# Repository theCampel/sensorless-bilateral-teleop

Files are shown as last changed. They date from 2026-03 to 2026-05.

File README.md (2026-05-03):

# Sensorless Bilateral Force Feedback for Low-Cost Scaled Teleoperation

A low-cost bimanual teleoperation platform that gives the operator bilateral force feedback without dedicated force sensors. Two commodity leader arms control two custom 2x-scaled 3D-printed follower arms; contact resistance is estimated from Dynamixel motor current and reflected back to the operator.

**[Preprint PDF](sensorless-bilateral-teleop.pdf)** | **[DOI](https://doi.org/10.13140/RG.2.2.31526.28487)** | **[Video](https://youtu.be/PqzKTUld3uw)** | **[Project page](https://leocamacho.co/teleop)**

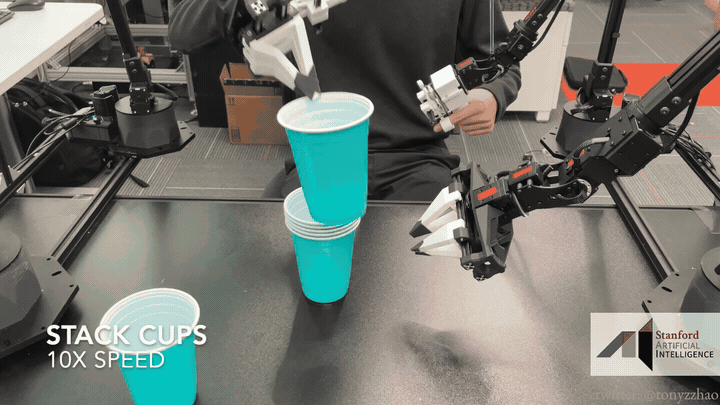
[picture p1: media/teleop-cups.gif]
The teleoperation system stacking cups with sensorless force feedback


## Key Results

- **91.1% obstacle detection sensitivity** via sensorless force feedback (n=22 user study)
- **~$3,000 total cost** for the complete dual-pair system (10x cheaper than ALOHA)
- **55% motor cost savings** via torque-tiered actuator selection
- **7/7 median learnability** rating from novice users

## Why It Matters

Low-cost imitation-learning systems such as ALOHA, GELLO, and the Koch arm made teleoperation cheaper, but most affordable platforms still lack haptic feedback. This project explores a narrower question: how far can bilateral feedback go if the only force signal available is motor current from commodity servos?

The answer is useful but bounded. Motor current is strong enough for operators to feel contact and detect hidden obstacles, but it cannot reliably distinguish gravity load from external contact without a dynamics model. The repository includes the ROS 2 control stack, 3D-printable follower arm links, the preprint, and the scripts used to create the README demo media.

## System Overview

| Component | Specification |
|---|---|
| Leaders (x2) | PincherX-100, all XL430-W250 motors, PWM mode (backdrivable) |
| Followers (x2) | Custom 2x-scaled, XM430-W210 (shoulder/elbow) + XL430-W250 (waist/wrist/gripper), position mode |
| Force feedback | Motor current as force proxy, 300 mA threshold, proportional PWM resistance |
| Software | ROS 2 Humble, 20 nodes across 4 namespaces, 100 Hz joint state publishing |
| Safety | Graceful shutdown (POSIX signal masking), smooth startup, gripper PWM limiting, invisible wall collision avoidance |

## Repository Structure

```
├── paper/                          # Preprint and figures
│   ├── paper.tex                   # LaTeX source
│   ├── paper.pdf                   # Compiled paper
│   ├── references.bib              # Bibliography
│   └── figures/                    # Paper figures
│
├── media/
│   └── teleop-cups.gif             # README demo GIF
│
├── scripts/
│   └── make_readme_gif.py          # Frame-range GIF generation helper
│
├── dissertation_ws/                # ROS 2 workspace
│   └── src/teleop_controller/
│       ├── teleop_controller/      # Python source
│       │   ├── teleop_node.py      # Joint-space teleoperation + collision avoidance
│       │   ├── force_feedback_node.py  # Sensorless bilateral force feedback
│       │   ├── motion_node.py      # Shared autonomy (RViz interactive markers)
│       │   └── effort_graph_node.py    # Real-time effort visualisation
│       ├── config/                 # Motor configs, teleop params, RViz config
│       ├── launch/                 # dual_arm_bringup.launch.py
│       └── urdf/                   # Scaled follower robot description
│
├── 3d-printing/                    # 3D printing files
│   ├── modified_arm/               # Custom 2x-scaled STLs (final versions)
│   │   ├── left-bicep.stl
│   │   ├── right-bicep.stl
│   │   ├── final-final-xl-forearm.stl
│   │   ├── left-final-gripper.stl
│   │   ├── right-final-gripper.stl
│   │   ├── left-finger-hold.stl
│   │   └── right-finger-hold.stl
│   └── px100-meshes/               # Original PincherX-100 reference meshes
│
└── identify_arms.py                # USB serial port identification utility
```

## Hardware Requirements

- 2x PincherX-100 Robot Arms (leaders)
- 4x XM430-W210 motors (follower shoulder + elbow)
- 6x XL430-W250 motors (follower waist + wrist + gripper)
- 4x U2D2 USB-to-serial adapters
- 12V power supply
- 3D-printed follower arm links (STLs in `3d-printing/modified_arm/`)

## Quick Start

### Prerequisites
- Ubuntu 22.04 with ROS 2 Humble
- [Interbotix XS SDK](https://docs.trossenrobotics.com/interbotix_xsarms_docs/)

### Set up USB latency and udev rules
```bash
python3 identify_arms.py
```

### Build and run
```bash
cd dissertation_ws
colcon build --packages-select teleop_controller
source install/setup.bash
ros2 launch teleop_controller dual_arm_bringup.launch.py
```

### Debug
```bash
ros2 node list
ros2 topic echo /leader_left/joint_states
ros2 topic echo /follower_left/joint_states
```

## Configuration

Teleoperation parameters are in `dissertation_ws/src/teleop_controller/config/teleop_config.yaml`:

| Parameter | Default | Description |
|---|---|---|
| `effort_threshold` | 300 mA | Effort below this is filtered |
| `pwm_scale` | 0.5 | Proportional gain for force feedback |
| `max_pwm` | 350 | Safety cap on leader resistance |
| `smoothing_alpha` | 0.15 | Exponential smoothing factor |
| `wall_threshold` | 0.0 m | Y-position of invisible wall |

## README Media

The demo GIF is generated from the full teleoperation video using a frame range:

```bash
python3 scripts/make_readme_gif.py /path/to/teleop_all.mp4 media/teleop-cups.gif \
  --start-frame 3000 \
  --end-frame 3180
```

## Citation

```bibtex
@misc{camacho2026sensorless,
  title={Sensorless Bilateral Force Feedback for Low-Cost Scaled Teleoperation},
  author={Camacho Pel\'aez, Leonardo},
  year={2026},
  doi={10.13140/RG.2.2.31526.28487},
  url={https://doi.org/10.13140/RG.2.2.31526.28487}
}
```

## License

This project is open-source. Hardware designs (STL files) and software are provided for research and educational use.

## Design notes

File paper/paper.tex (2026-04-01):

\documentclass[conference]{IEEEtran}

\usepackage{graphicx}
\usepackage{amsmath}
\usepackage{amssymb}
\usepackage{booktabs}
\usepackage{xcolor}
\usepackage{hyperref}
\usepackage{siunitx}
\usepackage{multirow}
\usepackage{subcaption}
\usepackage[font=small]{caption}
\usepackage{pifont}

\hypersetup{
  colorlinks=true,
  linkcolor=black,
  citecolor=[rgb]{0.0,0.35,0.65},
  urlcolor=[rgb]{0.0,0.35,0.65}
}

\title{Sensorless Bilateral Force Feedback for\\Low-Cost Scaled Teleoperation}

\author{\IEEEauthorblockN{Leonardo Camacho Pel\'{a}ez}
\IEEEauthorblockA{University of Edinburgh\\
\texttt{leocamacho707@gmail.com}}}

\makeatletter
\ifCLASSOPTIONconference
\def\@maketitle{\newpage
\bgroup\par\vskip\IEEEtitletopspace\vskip\IEEEtitletopspaceextra\centering%
   \vskip0.2em{\Huge\ifCLASSOPTIONtransmag\bfseries\LARGE\fi\@IEEEcompsoconly{\sffamily}\@IEEEcompsocconfonly{\normalfont\normalsize\vskip 2\@IEEEnormalsizeunitybaselineskip
   \bfseries\Large}\@IEEEcompsocnotconfonly{\vskip 0.75\@IEEEnormalsizeunitybaselineskip}\@title\par}\relax
   \@IEEEcompsocnotconfonly{\vskip 0.5\@IEEEnormalsizeunitybaselineskip}\vskip1.0em\par%
   {\@IEEEspecialpapernotice\mbox{}\vskip\@IEEEauthorblockconfadjspace%
    \mbox{}\hfill\begin{@IEEEauthorhalign}\@author\end{@IEEEauthorhalign}\hfill\mbox{}\par}\relax
   \vskip 1.2em
   \begin{minipage}{\textwidth}
      \centering
      
      \par\vspace{0.35em}
      {\footnotesize Fig.~1: \textbf{System overview.} (A)~The operator controls a PincherX-100 leader arm while the 2$\times$-scaled follower contacts an obstacle. (B)~Motor effort readings from the follower arm during obstacle contact: shoulder effort (dark) exceeds the 300\,mA feedback threshold (dashed), triggering proportional resistance at the leader. (C)~RViz visualisation showing leader and follower arm states in real time.\par}
   \end{minipage}\par
\par\addvspace{0.5\baselineskip}\egroup}
\fi
\makeatother

\begin{document}

\maketitle
\setcounter{figure}{0}
\refstepcounter{figure}\label{fig:hero}

% ===== ABSTRACT =====
\begin{abstract}
We present a bilateral teleoperation system in which two small commodity leader arms control two 3D-printed follower arms at twice the scale.
The followers use torque-tiered actuators---high-torque motors only at joints that demand them---saving 55\% on motor costs.
The complete four-arm platform costs approximately \$3{,}000, an order of magnitude less than comparable systems.
Unlike recent low-cost platforms (ALOHA, GELLO, Koch arm), ours provides force feedback: the leader arm experiences resistance when the follower contacts an object.
This is achieved exclusively using motor current as a force proxy, with no dedicated sensors.
In a study with 22 participants, operators detected real obstacles through force feedback with 91\% mean sensitivity and rated learnability at the maximum score (median 7/7).
The primary limitation is that motor current cannot distinguish gravity from contact---an extended arm produces the same signal as a collision.
We tested three alternative feedback policies to resolve this; each failed for a different physical reason, confirming that a dynamics model is required.
All source code, CAD files, and hardware documentation are released as open source at \url{https://leocamacho.co/teleop}.
\end{abstract}

% ===== INTRODUCTION =====
\section{Introduction}

In 1949, Raymond Goertz built the first mechanical bilateral manipulator at Argonne National Laboratory, allowing a human operator to handle radioactive materials while feeling the forces encountered by the remote arm~\cite{goertz1949}. Five years later, Goertz replaced the mechanical linkage with electrical servo coupling~\cite{goertz1954}, establishing the fundamental architecture that bilateral teleoperators still follow today: a leader arm that the operator moves, a follower arm that tracks it, and a feedback channel that communicates environment forces back to the operator's hand.

For decades, this architecture required industrial-grade hardware. A recent wave of low-cost systems has begun to change this. ALOHA~\cite{zhao2023aloha} demonstrated fine bimanual manipulation for approximately \$20,000 using commodity arms. GELLO~\cite{wu_2024_gello} built kinematically-matched leaders for under \$300. The Koch arm~\cite{koch2024} pushed the cost of a single leader-follower pair below \$250. These systems have enabled imitation learning at previously impossible scale.

However, all of these systems are \emph{unilateral}: the operator moves the leader, the follower tracks, and that is all. There is no force feedback channel. The reason is straightforward: bilateral control traditionally requires force/torque sensors (\$4,000--10,000 each) or carefully calibrated dynamics models. Neither is practical on commodity servo hardware. Recent concurrent work has begun to explore this gap~\cite{echo2025, sujit_2025_improving, kobayashi2024, kanai2025}, but a complete, low-cost bilateral system with custom-scaled hardware and an honest characterisation of its limits has been lacking.

We present a system that closes this gap by using motor current as a force proxy. Our contributions are:

\begin{enumerate}
    \item \textbf{Sensorless bilateral force feedback} on commodity Dynamixel servos, using motor current readings as a proportional force proxy. We achieve 91.1\% obstacle detection sensitivity in a user study without any dedicated force sensors. We characterise the electromagnetic braking effect that makes naive implementations fail.

    \item \textbf{Custom 2$\times$-scaled follower arms} with 3D-printed links and a torque-tiered motor configuration (high-torque XM430 at shoulder/elbow, low-torque XL430 elsewhere), reducing per-follower motor cost by 55\% versus a uniform design.

    \item \textbf{A complete dual-pair bimanual system} at $\sim$\$3,000 total---an order of magnitude cheaper than ALOHA---with collision avoidance, graceful shutdown, smooth startup, and shared autonomy.

    \item \textbf{An empirical characterisation of the gravity-contact ambiguity}: we evaluate three alternative feedback policies for handling gravity-induced false positives, each failing for a distinct physical reason, and identify model-based gravity compensation as the established solution.
\end{enumerate}

All hardware designs, source code, and CAD files are publicly available.\footnote{\url{https://github.com/theCampel/sensorless-bilateral-teleop}}

% ===== RELATED WORK =====
\section{Related Work}

\subsection{Low-Cost Teleoperation}

The past two years have seen rapid progress in accessible teleoperation. ALOHA~\cite{zhao2023aloha} paired ViperX-300 followers with custom Dynamixel-based leaders for bimanual manipulation, enabling Action Chunking with Transformers (ACT) for imitation learning. GELLO~\cite{wu_2024_gello} built 3D-printed kinematically-matched leaders for Franka, UR5, and xArm followers at under \$300 per leader. The Koch arm~\cite{koch2024} demonstrated that a single pair could be built for under \$250. U-ARM~\cite{zou_2025_uarm} and LeRobot~\cite{lerobot2025} further pushed accessibility.

All of these systems are unilateral. The operator sends commands; the follower executes them; there is no return channel. Our work adds bilateral force feedback to this class of system using only the hardware already present.

\subsection{Bilateral Control}

Bilateral teleoperation has a long theoretical history. Lawrence~\cite{lawrence_1993_stability} established the fundamental stability-transparency trade-off: perfect force transparency requires infinite controller stiffness, which is inherently destabilising. The four-channel bilateral architecture~\cite{hokayem2006} and wave variable methods~\cite{anderson1989} address time-delay stability but assume force sensing at both ends. Impedance control~\cite{hogan1985} provides a framework for contact interaction but again typically requires force measurements.

On commodity servo hardware, dedicated force sensors are impractical. Recent concurrent work has begun exploring sensorless alternatives: GELLO+Force~\cite{sujit_2025_improving} augments GELLO with strain-gauge-based force sensing on a Franka Panda, Bi-ACT~\cite{kobayashi2024} demonstrates the importance of bilateral feedback for imitation learning quality using disturbance observers at 1\,kHz, Echo~\cite{echo2025} proposes open-source force feedback, and IGBT~\cite{kanai2025} achieves sensorless bilateral control by clamping leader commands by follower effort magnitude. Our work differs in using only the motor current readings already available on standard Dynamixel servos, requiring no additional sensing hardware, and in building custom-scaled followers rather than using commercial off-the-shelf arms.

\subsection{Motor Current as Force Proxy}

Using motor current (or torque) as a proxy for external forces is well-established in industrial robotics~\cite{morante2016}. The approach works because motor current is proportional to torque output, which includes both the desired motion torque and any external disturbance. Matsumoto et al.~\cite{fast_bilateral2025} recently demonstrated fast bilateral teleoperation using accurate dynamics models for sensorless force estimation. However, without a dynamics model, the raw current signal includes gravitational, inertial, and frictional components that cannot be separated from external contact forces---a limitation we characterise in detail.

% ===== SYSTEM DESIGN =====
\section{System Design}

\subsection{Overview}

Our system consists of two leader-follower pairs operating simultaneously (Fig.~\ref{fig:hero}). Each pair comprises a standard PincherX-100~\cite{px100specs} leader arm (5-DOF, all XL430-W250 motors~\cite{xl430manual}) and a custom 2$\times$-scaled follower arm. The leaders operate in PWM mode (backdrivable), while the followers operate in position mode, tracking leader joint angles via 1:1 joint-space mapping. A software-based invisible wall at the workspace centreline prevents the two followers from colliding. The entire system runs on ROS~2 Humble~\cite{macenski_2022_robot}.

\subsection{Custom Scaled Followers}

Rather than purchasing larger commercial arms, we designed and 3D-printed custom follower arms at 2$\times$ the PincherX-100's link lengths (Fig.~\ref{fig:hardware}). This required decomposing the original STL meshes into motor mounts (kept at original scale to fit unmodified motors) and arm segments (scaled 2$\times$). Naive uniform scaling would have enlarged the motor cavities beyond the physical motor dimensions.

\textbf{Torque-tiered motor selection.}
Scaling laws dictate that bending moments at joints grow with the square of link length~\cite{waldron2000, dermitzakis2011}. At 2$\times$ scale, the shoulder and elbow joints require roughly 4$\times$ the torque of the original PincherX-100. We address this with a mixed-motor design:

\begin{itemize}
    \item \textbf{Shoulder and elbow}: XM430-W210 motors~\cite{xm430manual} (3.0\,Nm stall torque, \$333 each)
    \item \textbf{Waist, wrist, and gripper}: XL430-W250 motors~\cite{xl430manual} (1.5\,Nm stall torque, \$27.50 each)
\end{itemize}

This torque-tiered approach costs \$749 per follower in motors, compared to \$1,665 for uniform XM430s---a 55\% reduction. The complete dual-pair system (4 arms, power supplies, USB adapters, 3D-printed parts) totals approximately \$3,000.

\begin{figure}[t]
    \centering
    
    \caption{\textbf{Hardware comparison.} Standard PincherX-100 leader (right) alongside the custom 2$\times$-scaled follower (left). High-torque XM430 motors (green labels) at shoulder and elbow handle the increased loads; lower-cost XL430 motors serve the remaining joints.}
    \label{fig:hardware}
\end{figure}

\subsection{Software Architecture}

The system comprises 10 ROS~2 nodes per arm pair (20 total), each in an explicit namespace to prevent topic collisions:

\begin{itemize}
    \item \texttt{xs\_sdk} nodes for leader and follower motor control (100\,Hz joint state publishing)
    \item \texttt{robot\_state\_publisher} nodes for TF frame broadcasting
    \item \texttt{teleop\_node} for joint-space mapping and collision avoidance
    \item \texttt{force\_feedback\_node} for bilateral current-based feedback
    \item \texttt{motion\_node} for shared autonomy via RViz interactive markers
\end{itemize}

USB serial latency is set to 1\,ms (from the 16\,ms default~\cite{ftdi_latency}) via persistent \texttt{udev} rules. Each arm has a dedicated serial port mapped deterministically to \texttt{/dev/ttyDXL\{0--3\}}.

\subsection{Sensorless Force Feedback}
\label{sec:force_feedback}

Our bilateral force feedback uses motor current (``effort'' in Dynamixel terminology) as a proxy for external forces. The follower's \texttt{xs\_sdk} publishes effort values (in mA) for each joint at 100\,Hz. The force feedback node applies a proportional resistance law:

\begin{equation}
    \text{PWM}_{\text{leader},j} = \begin{cases}
        -\text{sgn}(e_j) \cdot \min\!\big((|e_j| - \theta) \cdot k,\; P_{\max}\big) & \text{if } |e_j| > \theta \\
        0 & \text{otherwise}
    \end{cases}
    \label{eq:feedback}
\end{equation}

where $e_j$ is the follower effort on joint $j$, $\theta = 300$\,mA is the effort threshold (filtering noise and low-load motion), $k = 0.5$ is the proportional gain, and $P_{\max} = 350$ is a safety cap ($\approx$40\% of the $\pm$885 PWM range). The resulting PWM is exponentially smoothed with $\alpha = 0.15$ before being sent to the leader motor as a resisting torque. The leader must be in PWM mode with torque enabled for this to work, which introduces electromagnetic braking as a side effect (Section~\ref{sec:gravity}).

\textbf{Electromagnetic braking trade-off.} Enabling torque on the leader motors (required for PWM-based force feedback) introduces electromagnetic braking via slow-decay H-bridge behaviour~\cite{srikanth2008, colgate1994}. When the motor is backdriven, back-EMF through the H-bridge creates a velocity-dependent resistance amplified by $N^2$ through the gearbox---for the XL430's 258.5:1 ratio, this amplification is approximately 67{,}000. This increases the baseline resistance the operator feels, reducing backdrivability. This is a hardware-level manifestation of Lawrence's stability-transparency trade-off~\cite{lawrence_1993_stability}: force feedback requires torque-enabled motors, which reduces transparency. ALOHA\,2~\cite{aloha2_2024} addressed a similar problem by replacing the leader gripper motor with a lower gear-ratio variant, achieving a 10$\times$ reduction in backdriving force.

\subsection{Safety Systems}

Three safety mechanisms protect the hardware:

\textbf{Graceful shutdown.} The follower \texttt{xs\_sdk} processes are launched with POSIX \texttt{SIG\_BLOCK} signal masks, preventing Ctrl+C from killing the motor controller before the teleop node can command a smooth return to the sleep position over 1.5\,s. This prevents the 2$\times$-scaled arms from crashing under their own weight.

\textbf{Smooth startup.} On the first leader message, the follower's Profile Velocity is temporarily set to 1,500\,ms (slow), allowing a gradual move to the leader's position before restoring the responsive 50\,ms setting.

\textbf{Gripper protection.} A hardware PWM limit of 300 ($\sim$34\% of maximum) is set on follower gripper motors to prevent stalling when gripping objects harder than the leader can close.

\subsection{Collision Avoidance}

A software-based invisible wall at the workspace centreline ($Y = 0$) prevents the two followers from colliding during bimanual operation. Each teleop node queries the TF tree~\cite{foote2013tf} for its follower's gripper position at 30\,Hz. When the gripper crosses the wall threshold, all follower joints are frozen. Resumption uses 5\% per-frame blending of the leader's target position to prevent jerky snap-back when the operator retreats.

% ===== EXPERIMENTS =====
\section{Experiments}

\subsection{Study Design}

We conducted a user study with 22 participants (university students, ages 18--24, no prior teleoperation experience) to evaluate the force feedback system. The study comprised:

\begin{enumerate}
    \item A \textbf{perception survey} (5 questions, 7-point Likert scale~\cite{preston2000}) assessing the operator's subjective experience of force feedback.
    \item An \textbf{obstacle detection task} ($n = 14$ with per-trial data) where participants reported whether they felt an obstacle during each of six teleoperation trials (three with obstacles, three without).
\end{enumerate}

Participants received a brief demonstration and 2 minutes of free practice before the evaluation.

\subsection{Perception Results}

Table~\ref{fig:survey} summarises the Likert responses. The strongest result was \textbf{learnability} (Q4: ``The system was easy to learn''): median 7/7, with 14 of 22 participants giving the maximum rating. Participants also rated obstacle detection positively (Q1: median 6/7) and found the feedback useful for task awareness (Q3: median 6/7). The lowest-rated item was Q2 (``I could distinguish obstacles from general stiffness''), reflecting the gravity-contact ambiguity discussed in Section~\ref{sec:gravity}.

\begin{table}[t]
    \centering
    \caption{Perception survey results ($n = 22$, 7-point Likert scale).}
    \label{fig:survey}
    \small
    \begin{tabular}{@{}lcccc@{}}
        \toprule
        \textbf{Question} & \textbf{Med.} & \textbf{IQR} & \textbf{Mean} & \textbf{SD} \\
        \midrule
        Q1: Could feel contact & 6 & 1.0 & 6.23 & 0.81 \\
        Q2: Distinguish obstacle from stiffness & 6 & 2.0 & 5.64 & 1.26 \\
        Q3: Feedback useful for awareness & 6 & 1.0 & 6.09 & 0.97 \\
        Q4: System easy to learn & \textbf{7} & 1.0 & \textbf{6.50} & 0.80 \\
        Q5: Felt in control & 6 & 2.0 & 5.91 & 0.87 \\
        \bottomrule
    \end{tabular}
\end{table}

\subsection{Obstacle Detection Performance}

Of the 14 participants with per-trial obstacle detection data (84 total trials):

\begin{itemize}
    \item \textbf{Sensitivity}: 91.1\% $\pm$ 14.8\% (obstacle present, correctly detected)
    \item \textbf{Specificity}: 81.0\% $\pm$ 33.9\% (no obstacle, correctly identified)
    \item \textbf{Accuracy}: 85.7\% $\pm$ 18.3\%
\end{itemize}

Seven participants achieved perfect accuracy on all trials. The variance in specificity is explained by the gravity problem: four participants had elevated false positive rates, reporting obstacles when none were present but the arm was in an extended posture generating high gravitational effort.

\subsection{Qualitative Feedback}

Thematic analysis of open-ended responses revealed five themes: gripper difficulty (10/22 mentions---the dominant complaint, attributable to gearbox friction in the XL430's 258.5:1 gearbox rather than force feedback design), gravity/resistance confusion (6/22), positive usability (5/22: ``very intuitive,'' ``very responsive''), fear of hardware damage (2/22), and ergonomic concerns (2/22). The gripper complaint concerns the leader arm's physical ergonomics, not the teleoperation control or force feedback algorithm.

% ===== THE GRAVITY PROBLEM =====
\section{The Gravity-Contact Ambiguity}
\label{sec:gravity}

The central limitation of sensorless bilateral feedback on commodity hardware is that motor current conflates multiple physical phenomena: gravitational torque, contact forces, friction, inertia, and electromagnetic braking. The proportional effort approach (Section~\ref{sec:force_feedback}) works well for obstacles at non-extreme postures but triggers false feedback when the arm is extended horizontally, where gravity alone produces 400--600\,mA at the shoulder (Fig.~\ref{fig:effort_comparison}).

\begin{figure}[t]
    \centering
    \begin{subfigure}[b]{\columnwidth}
        \centering
        
        \caption{Obstacle contact: shoulder effort exceeds the 300\,mA threshold.}
        \label{fig:effort_contact}
    \end{subfigure}
    \vspace{0.3em}
    \begin{subfigure}[b]{\columnwidth}
        \centering
        
        \caption{Gravity false positive: arm extended horizontally with no obstacle, shoulder effort sustained above threshold due to gravitational load alone.}
        \label{fig:effort_gravity}
    \end{subfigure}
    \caption{\textbf{The gravity-contact ambiguity.} Both scenarios produce effort readings above the 300\,mA feedback threshold (dashed line), but only (a) involves actual obstacle contact. Motor current alone cannot distinguish between these cases.}
    \label{fig:effort_comparison}
\end{figure}

We attempted three alternative gating strategies, each addressing a different aspect of the problem.

\textbf{1. Effort derivative gating}: react to the \emph{rate of change} of follower effort rather than its absolute magnitude, hypothesising that contact produces rapid spikes while gravity changes slowly. This filtered some gravity false positives during slow movements but failed on slow or compliant contacts, which produce small derivatives indistinguishable from normal gravity variation. Differentiating the signal also amplifies sensor noise, producing jittery feedback that requires heavy smoothing---reintroducing the latency this approach was meant to avoid.

\textbf{2. Position error detection}: monitor the tracking error between leader and follower joint angles. If the follower falls behind (cannot reach the commanded position), something is blocking it. This partly solves the gravity problem---the follower still tracks under gravitational load, so the error stays small. But feedback is sluggish: error accumulates only \emph{after} the follower physically fails to track, introducing latency that makes the system feel unresponsive.

\textbf{3. Follower velocity detection}: apply resistance only when the follower has near-zero velocity and high effort---the condition indicating a physical obstacle. During motion under gravity, the follower tracks the leader (non-zero velocity), so no false positive occurs. But whenever the operator \emph{pauses} with the arm extended, zero velocity plus high effort from gravity is indistinguishable from zero velocity plus high effort from an obstacle.

The common failure mode is clear: the combined motor current signal $e_j$ includes a gravitational component $g_j(\mathbf{q})$ that depends on joint configuration $\mathbf{q}$. Without computing $g_j(\mathbf{q})$ via inverse dynamics (e.g., Recursive Newton-Euler~\cite{lynch2017modern}), there is no way to isolate the contact force component. This explains why industrial bilateral systems use either dedicated force sensors or accurate dynamics models~\cite{fast_bilateral2025}---and why existing low-cost systems have avoided bilateral feedback entirely.

We consider this characterisation itself a contribution: it establishes a \emph{necessary condition} for robust sensorless bilateral control and explains clearly why commodity servos cannot achieve it without additional computation.

% ===== DISCUSSION =====
\section{Discussion}

\subsection{Comparison with Existing Systems}

Table~\ref{tab:comparison} positions our system against related work. We are, to our knowledge, the only system that combines custom-built scaled followers, bilateral force feedback, and bimanual operation below \$5,000.

\begin{table}[t]
    \centering
    \caption{Comparison with recent low-cost teleoperation systems, with costs normalised to a dual-pair configuration where possible.}
    \label{tab:comparison}
    \small
    \begin{tabular}{@{}lccccc@{}}
        \toprule
        \textbf{System} & \textbf{Cost} & \textbf{Bi.} & \textbf{Bim.} & \textbf{Custom} & \textbf{F/T} \\
        \midrule
        ALOHA~\cite{zhao2023aloha} & \$20k & \ding{55} & \ding{51} & Leaders & \ding{55} \\
        GELLO~\cite{wu_2024_gello} & $<$\$1k\textsuperscript{*} & \ding{55} & \ding{51} & Leaders & \ding{55} \\
        Koch~\cite{koch2024} & \$860\textsuperscript{\dag} & \ding{55} & \ding{55} & Both & \ding{55} \\
        GELLO+Force~\cite{sujit_2025_improving} & \$60k+\textsuperscript{\dag} & \ding{51} & \ding{55} & Leaders & \ding{51} \\
        IGBT~\cite{kanai2025} & N/R & \ding{51} & \ding{55} & \ding{55} & \ding{55} \\
        Bi-ACT~\cite{kobayashi2024} & \$9k & \ding{51} & \ding{51} & \ding{55} & \ding{55} \\
        \textbf{Ours} & \textbf{\$3k} & \ding{51} & \ding{51} & \textbf{Followers} & \ding{55} \\
        \bottomrule
    \end{tabular}
    \vspace{-0.5em}
    \begin{flushleft}
    \footnotesize Bi.~= Bilateral feedback. Bim.~= Bimanual. F/T~= Dedicated force/torque sensor.\\
    \textsuperscript{*}Leader hardware only; requires a separate follower arm (\$10k--\$45k each).\\
    \textsuperscript{\dag}Extrapolated: single-pair cost $\times$\,2.
    \end{flushleft}
\end{table}

\subsection{Lessons for Systems Builders}

Three practical lessons emerged:

\textbf{Integration dominates.} Individual subsystems (teleop, force feedback, collision avoidance) each worked in isolation. Combining four arms into a single ROS~2 graph exposed namespace leaks, udev conflicts, and startup race conditions that took longer to resolve than any individual feature. The gap between ``one pair works'' and ``two pairs work reliably'' was wider than any individual subsystem challenge.

\textbf{Hardware limitations propagate.} The gripper's gearbox friction (the dominant user complaint) is a mechanical property of the XL430 motor, not a software issue. The mixed motor configuration saved 55\% on costs but prevented uniform gravity compensation: XL430 motors lack the current control mode needed for model-based torque estimation. No amount of algorithmic tuning can fix hardware-fundamental constraints. Identifying \emph{which} limitations are hardware-fundamental versus software-addressable saves engineering time.

\textbf{Negative results are load-bearing.} Our three failed force feedback approaches each reveal a different facet of the gravity-contact ambiguity. Documenting \emph{why} they fail provides more actionable guidance than documenting only the approach that worked.

% ===== CONCLUSION =====
\section{Conclusion}

We presented a low-cost bilateral teleoperation system that achieves sensorless force feedback using motor current readings from commodity Dynamixel servos. The system pairs standard PincherX-100 leaders with custom 2$\times$-scaled 3D-printed followers using a torque-tiered motor design, achieving bimanual bilateral teleoperation at $\sim$\$3,000---an order of magnitude cheaper than comparable systems. A user study demonstrated 91.1\% obstacle detection sensitivity and strong perceived learnability (median 7/7). We characterised the fundamental gravity-contact ambiguity that limits sensorless bilateral control and documented three alternative approaches that fail to resolve it, establishing that a dynamics model is a necessary condition for robust force estimation on commodity hardware.

\textbf{Future work.} Gravity compensation via Recursive Newton-Euler inverse dynamics would address the core limitation. Lower gear-ratio motors or series elastic actuators would reduce electromagnetic braking. The system's 1:1 joint-space mapping and ROS~2 architecture make it directly compatible with imitation learning frameworks such as ACT~\cite{zhao2023aloha} and LeRobot~\cite{lerobot2025}, where bilateral demonstrations could improve policy quality~\cite{kobayashi2024}.

\section*{Acknowledgements}
The author thanks Garry Ellard for supervision and guidance throughout this project, and the 22 user study participants. This work was conducted as a final-year undergraduate dissertation at the University of Edinburgh.

\bibliographystyle{IEEEtran}
\bibliography{references}

\end{document}

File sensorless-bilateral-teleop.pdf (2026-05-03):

# Sensorless Bilateral Force Feedback for Low-Cost Scaled Teleoperation

Leonardo Camacho Pelaez ´
University of Edinburgh
leocamacho707@gmail.com

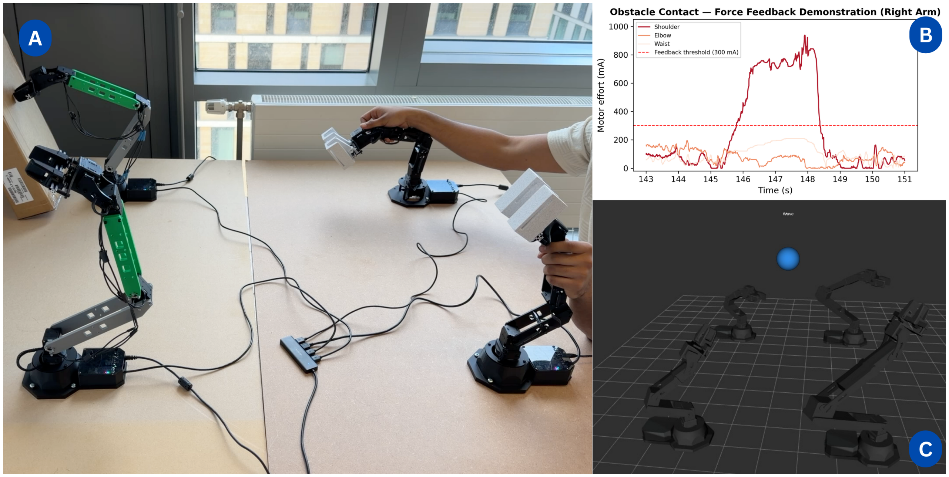
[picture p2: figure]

Fig. 1: System overview. (A) The operator controls a PincherX-100 leader arm while the 2×-scaled follower contacts an obstacle. (B) Motor effort readings from the follower arm during obstacle contact: shoulder effort (dark) exceeds the 300 mA feedback threshold (dashed), triggering proportional resistance at the leader. (C) RViz visualisation showing leader and follower arm states in real time.

Abstract—We present a bilateral teleoperation system in
which two small commodity leader arms control two 3D-printed follower arms at twice the scale. The followers use torque-tiered actuators—high-torque motors only at joints that demand them—saving 55% on motor costs. The complete four-arm platform costs approximately $3,000, an order of magnitude less than comparable systems. Unlike recent low-cost platforms (ALOHA, GELLO, Koch arm), ours provides force feedback: the leader arm experiences resistance when the follower contacts an object. This is achieved exclusively using motor current as a force proxy, with no dedicated sensors. In a study with 22 participants, operators detected real obstacles through force feedback with 91% mean sensitivity and rated learnability at the maximum score (median 7/7). The primary limitation is that motor current cannot distinguish gravity from contact—an extended arm produces the same signal as a collision. We tested three alternative feedback policies to resolve this; each failed for a different physical reason, confirming that a dynamics model is required. All source code, CAD files, and hardware documentation are released as open source at https://leocamacho.co/teleop.
I. INTRODUCTION

In 1949, Raymond Goertz built the first mechanical bilateral manipulator at Argonne National Laboratory, allowing a human operator to handle radioactive materials while feeling the forces encountered by the remote arm [1]. Five years later, Goertz replaced the mechanical linkage with electrical servo coupling [2], establishing the fundamental architecture that bilateral teleoperators still follow today: a leader arm that the operator moves, a follower arm that tracks it, and a feedback channel that communicates environment forces back to the operator’s hand.
For decades, this architecture required industrial-grade hardware. A recent wave of low-cost systems has begun to change this. ALOHA [3] demonstrated fine bimanual manipulation for approximately $20,000 using commodity arms. GELLO [4] built kinematically-matched leaders for under $300. The Koch arm [5] pushed the cost of a single leader-follower pair below $250. These systems have enabled imitation learning at previously impossible scale.

However, all of these systems are unilateral: the operator moves the leader, the follower tracks, and that is all. There is no force feedback channel. The reason is straightforward: bilateral control traditionally requires force/torque sensors ($4,000–10,000 each) or carefully calibrated dynamics models. Neither is practical on commodity servo hardware. Recent concurrent work has begun to explore this gap [6], [7], [8], [9], but a complete, low-cost bilateral system with custom-scaled hardware and an honest characterisation of its limits has been lacking.
We present a system that closes this gap by using motor current as a force proxy. Our contributions are:
1) Sensorless bilateral force feedback on commodity Dynamixel servos, using motor current readings as a proportional force proxy. We achieve 91.1% obstacle detection sensitivity in a user study without any dedicated force sensors. We characterise the electromagnetic braking effect that makes naive implementations fail.
2) Custom 2×-scaled follower arms with 3D-printed links and a torque-tiered motor configuration (high-torque XM430 at shoulder/elbow, low-torque XL430 elsewhere), reducing per-follower motor cost by 55% versus a uniform design.
3) A complete dual-pair bimanual system at ∼$3,000 total—an order of magnitude cheaper than ALOHA— with collision avoidance, graceful shutdown, smooth startup, and shared autonomy.
4) An empirical characterisation of the gravity-contact ambiguity: we evaluate three alternative feedback policies for handling gravity-induced false positives, each failing for a distinct physical reason, and identify model-based gravity compensation as the established solution. All hardware designs, source code, and CAD files are publicly available.¹

II. RELATED WORK
A. Low-Cost Teleoperation
The past two years have seen rapid progress in accessible teleoperation. ALOHA [3] paired ViperX-300 followers with custom Dynamixel-based leaders for bimanual manipulation, enabling Action Chunking with Transformers (ACT) for imitation learning. GELLO [4] built 3D-printed kinematically-matched leaders for Franka, UR5, and xArm followers at under $300 per leader. The Koch arm [5] demonstrated that a single pair could be built for under $250. U-ARM [10] and LeRobot [11] further pushed accessibility.
All of these systems are unilateral. The operator sends commands; the follower executes them; there is no return channel. Our work adds bilateral force feedback to this class of system using only the hardware already present.
B. Bilateral Control
Bilateral teleoperation has a long theoretical history.
Lawrence | [12] | established the | fundamental stability-
transparency trade-off: perfect force transparency requires

1https://github.com/theCampel/sensorless-bilateral-teleop

infinite controller stiffness, which is inherently destabilising. The four-channel bilateral architecture [13] and wave variable methods [14] address time-delay stability but assume force sensing at both ends. Impedance control [15] provides a framework for contact interaction but again typically requires force measurements.
On commodity servo hardware, dedicated force sensors are impractical. Recent concurrent work has begun exploring sensorless alternatives: GELLO+Force [7] augments GELLO with strain-gauge-based force sensing on a Franka Panda, Bi-ACT [8] demonstrates the importance of bilateral feedback for imitation learning quality using disturbance observers at 1 kHz, Echo [6] proposes open-source force feedback, and IGBT [9] achieves sensorless bilateral control by clamping leader commands by follower effort magnitude. Our work differs in using only the motor current readings already available on standard Dynamixel servos, requiring no additional sensing hardware, and in building custom-scaled followers rather than using commercial off-the-shelf arms.
C. Motor Current as Force Proxy
Using motor current (or torque) as a proxy for external forces is well-established in industrial robotics [16]. The approach works because motor current is proportional to torque output, which includes both the desired motion torque and any external disturbance. Matsumoto et al. [17] recently demonstrated fast bilateral teleoperation using accurate dynamics models for sensorless force estimation. However, without a dynamics model, the raw current signal includes gravitational, inertial, and frictional components that cannot be separated from external contact forces—a limitation we characterise in detail.

III. SYSTEM DESIGN

A. Overview
Our system consists of two leader-follower pairs operating simultaneously (Fig. 1). Each pair comprises a standard PincherX-100 [18] leader arm (5-DOF, all XL430-W250 motors [19]) and a custom 2×-scaled follower arm. The leaders operate in PWM mode (backdrivable), while the followers operate in position mode, tracking leader joint angles via 1:1 joint-space mapping. A software-based invisible wall at the workspace centreline prevents the two followers from colliding. The entire system runs on ROS 2 Humble [20].
B. Custom Scaled Followers
Rather than purchasing larger commercial arms, we designed and 3D-printed custom follower arms at 2× the PincherX-100’s link lengths (Fig. 2). This required decomposing the original STL meshes into motor mounts (kept at original scale to fit unmodified motors) and arm segments (scaled 2×). Naive uniform scaling would have enlarged the motor cavities beyond the physical motor dimensions. Torque-tiered motor selection. Scaling laws dictate that bending moments at joints grow with the square of link length [21], [22]. At 2× scale, the shoulder and elbow joints

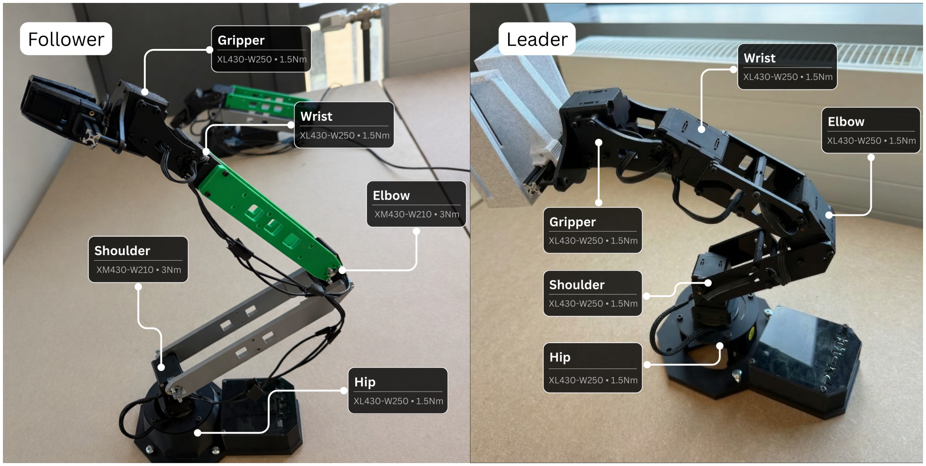
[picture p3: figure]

Fig. 2: Hardware comparison. Standard PincherX-100 leader (right) alongside the custom 2×-scaled follower (left). High-torque XM430 motors (green labels) at shoulder and elbow handle the increased loads; lower-cost XL430 motors serve the remaining joints.

require roughly 4× the torque of the original PincherX-100. We address this with a mixed-motor design:
- Shoulder and elbow: XM430-W210 motors [23] (3.0 Nm stall torque, $333 each)
- Waist, wrist, and gripper: XL430-W250 motors [19] (1.5 Nm stall torque, $27.50 each)
This torque-tiered approach costs $749 per follower in motors, compared to $1,665 for uniform XM430s—a 55% reduction. The complete dual-pair system (4 arms, power supplies, USB adapters, 3D-printed parts) totals approximately $3,000.
C. Software Architecture

The system comprises 10 ROS 2 nodes per arm pair (20 total), each in an explicit namespace to prevent topic collisions:
- xs_sdk nodes for leader and follower motor control (100 Hz joint state publishing)
- robot_state_publisher nodes for TF frame
broadcasting
- teleop_node for joint-space mapping and collision avoidance
- force_feedback_node for bilateral current-based feedback
- motion_node for shared autonomy via RViz interactive markers
USB serial latency is set to 1 ms (from the 16 ms default [24]) via persistent udev rules. Each arm has a dedicated serial port mapped deterministically to
/dev/ttyDXL{0--3}.
D. Sensorless Force Feedback

Our bilateral force feedback uses motor current (“effort” in Dynamixel terminology) as a proxy for external forces. The follower’s xs_sdk publishes effort values (in mA) for each joint at 100 Hz. The force feedback node applies a proportional resistance law:

PWMleader,j =

(
−sgn(ej ) · min
(|ej | − θ) · k, Pmax
if |ej | > θ
0 | otherwise (1)

where ej is the follower effort on joint j, θ = 300 mA is the effort threshold (filtering noise and low-load motion), k = 0.5 is the proportional gain, and Pmax = 350 is a safety cap (≈40% of the ±885 PWM range). The resulting PWM is exponentially smoothed with α = 0.15 before being sent to the leader motor as a resisting torque. The leader must be in PWM mode with torque enabled for this to work, which introduces electromagnetic braking as a side effect (Section V). Electromagnetic braking trade-off. Enabling torque on the leader motors (required for PWM-based force feedback) introduces electromagnetic braking via slow-decay H-bridge behaviour [25], [26]. When the motor is backdriven, back-EMF through the H-bridge creates a velocity-dependent
resistance amplified by N² | through the gearbox—for the
XL430’s 258.5:1 ratio, this amplification is approximately 67,000. This increases the baseline resistance the operator feels, reducing backdrivability. This is a hardware-level manifestation of Lawrence’s stability-transparency trade-off [12]: force feedback requires torque-enabled motors, which reduces transparency. ALOHA 2 [27] addressed a similar problem by replacing the leader gripper motor with a lower gear-ratio variant, achieving a 10× reduction in backdriving force.
E. Safety Systems

Three safety mechanisms protect the hardware:
Graceful shutdown. The follower xs_sdk processes are launched with POSIX SIG_BLOCK signal masks, preventing Ctrl+C from killing the motor controller before the teleop node can command a smooth return to the sleep position over 1.5 s. This prevents the 2×-scaled arms from crashing under their own weight.
Smooth startup. On the first leader message, the follower’s Profile Velocity is temporarily set to 1,500 ms (slow), allowing a gradual move to the leader’s position before restoring the responsive 50 ms setting.
Gripper protection. A hardware PWM limit of 300 (∼34% of maximum) is set on follower gripper motors to prevent stalling when gripping objects harder than the leader can close.
F. Collision Avoidance

A software-based invisible wall at the workspace centreline (Y = 0) prevents the two followers from colliding during bimanual operation. Each teleop node queries the TF tree [28] for its follower’s gripper position at 30 Hz. When the gripper crosses the wall threshold, all follower joints are frozen. Resumption uses 5% per-frame blending of the leader’s target position to prevent jerky snap-back when the operator retreats.

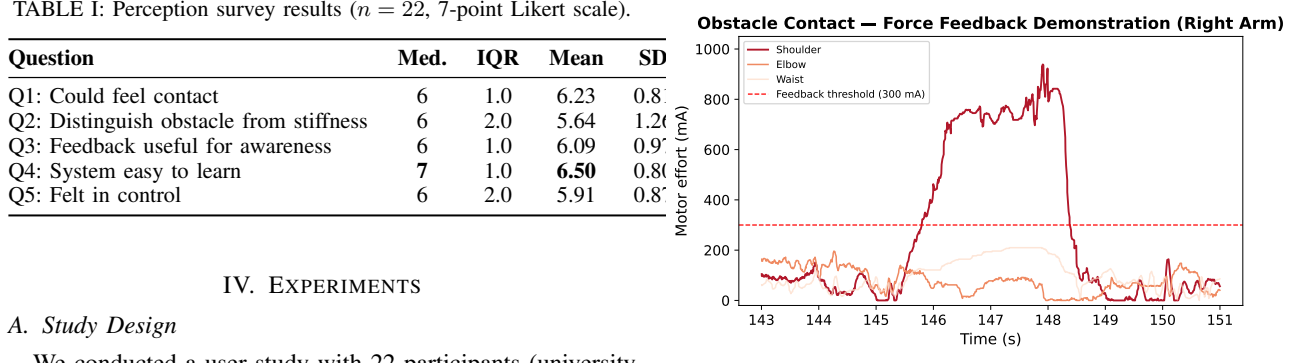
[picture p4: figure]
Question; Med.; IQR; Mean; Q1: Could feel contact; Q2: Distinguish obstacle from stiffness; Q3: Feedback useful for awareness; Q4: System easy to learn; Q5: Felt in control; IV. EXPERIMENTS; A. Study Design; Time (s); Motor effort (mA); Obstacle Contact; Force Feedback Demonstration (Right Arm); Shoulder Elbow Waist Feedback threshold (300 mA)

TABLE I: Perception survey results (n = 22, 7-point Likert scale).

We conducted a user study with 22 participants (university students, ages 18–24, no prior teleoperation experience) to evaluate the force feedback system. The study comprised:
1) A perception survey (5 questions, 7-point Likert scale [29]) assessing the operator’s subjective experience of force feedback.
2) An obstacle detection task (n = 14 with per-trial data) where participants reported whether they felt an obstacle during each of six teleoperation trials (three with obstacles, three without).
Participants received a brief demonstration and 2 minutes of free practice before the evaluation.
B. Perception Results
Table I summarises the Likert responses. The strongest result was learnability (Q4: “The system was easy to learn”): median 7/7, with 14 of 22 participants giving the maximum rating. Participants also rated obstacle detection positively (Q1: median 6/7) and found the feedback useful for task awareness (Q3: median 6/7). The lowest-rated item was Q2 (“I could distinguish obstacles from general stiffness”), reflecting the gravity-contact ambiguity discussed in Section V.
C. Obstacle Detection Performance
Of the 14 participants with per-trial obstacle detection data (84 total trials):
- Sensitivity: 91.1% ± 14.8% (obstacle present, correctly detected)
- Specificity: 81.0% ± 33.9% (no obstacle, correctly identified)
- Accuracy: 85.7% ± 18.3%
Seven participants achieved perfect accuracy on all trials. The variance in specificity is explained by the gravity problem: four participants had elevated false positive rates, reporting obstacles when none were present but the arm was in an extended posture generating high gravitational effort.
D. Qualitative Feedback
Thematic analysis of open-ended responses revealed five themes: gripper difficulty (10/22 mentions—the dominant complaint, attributable to gearbox friction in the XL430’s 258.5:1 gearbox rather than force feedback design), gravity/resistance confusion (6/22), positive usability (5/22: “very intuitive,” “very responsive”), fear of hardware damage (2/22),
(a) Obstacle contact: shoulder effort exceeds the 300 mA threshold.

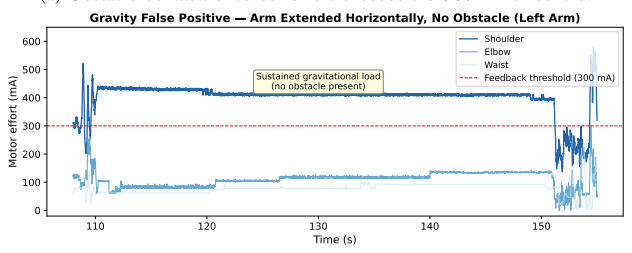
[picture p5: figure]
Time (s); Motor effort (mA); Sustained gravitational load (no obstacle present); Shoulder Elbow Waist Feedback threshold (300 mA)

Gravity False Positive Arm Extended Horizontally, No Obstacle (Left Arm)

(b) Gravity false positive: arm extended horizontally with no obstacle, shoulder effort sustained above threshold due to gravitational load alone.

Fig. 3: The gravity-contact ambiguity. Both scenarios produce effort readings above the 300 mA feedback threshold (dashed line), but only (a) involves actual obstacle contact. Motor current alone cannot distinguish between these cases.

and ergonomic concerns (2/22). The gripper complaint concerns the leader arm’s physical ergonomics, not the teleoperation control or force feedback algorithm.

V. THE GRAVITY-CONTACT AMBIGUITY
The central limitation of sensorless bilateral feedback on commodity hardware is that motor current conflates multiple physical phenomena: gravitational torque, contact forces, friction, inertia, and electromagnetic braking. The proportional effort approach (Section III-D) works well for obstacles at non-extreme postures but triggers false feedback when the arm is extended horizontally, where gravity alone produces 400– 600 mA at the shoulder (Fig. 3).
We attempted three alternative gating strategies, each addressing a different aspect of the problem.

### 1. Effort derivative gating: react to the rate of change

of follower effort rather than its absolute magnitude, hypothesising that contact produces rapid spikes while gravity changes slowly. This filtered some gravity false positives during slow movements but failed on slow or compliant contacts, which produce small derivatives indistinguishable from normal gravity variation. Differentiating the signal also amplifies sensor noise, producing jittery feedback that requires heavy smoothing—reintroducing the latency this approach was meant to avoid.

### 2. Position error detection: monitor the tracking error

between leader and follower joint angles. If the follower falls

TABLE II: Comparison with recent low-cost teleoperation systems, with costs normalised to a dual-pair configuration where possible.

System | Cost | Bi. | Bim. | Custom | F/T
ALOHA [3] | $20k | ✗ | ✓ | Leaders | ✗
GELLO [4] | <$1k* | ✗ | ✓ | Leaders | ✗
Koch [5] | $860† | ✗ | ✗ | Both | ✗
GELLO+Force [7] | $60k+† | ✓ | ✗ | Leaders | ✓
IGBT [9] | N/R | ✓ | ✗ | ✗ | ✗
Bi-ACT [8] | $9k | ✓ | ✓ | ✗ | ✗
Ours | $3k | ✓ | ✓ | Followers | ✗

Bi. = Bilateral feedback. Bim. = Bimanual. F/T = Dedicated force/torque sensor.
*Leader hardware only; requires a separate follower arm ($10k–$45k each). †Extrapolated: single-pair cost × 2.

behind (cannot reach the commanded position), something is blocking it. This partly solves the gravity problem—the follower still tracks under gravitational load, so the error stays small. But feedback is sluggish: error accumulates only after the follower physically fails to track, introducing latency that makes the system feel unresponsive.

### 3. Follower velocity detection: apply resistance only when

the follower has near-zero velocity and high effort—the condition indicating a physical obstacle. During motion under gravity, the follower tracks the leader (non-zero velocity), so no false positive occurs. But whenever the operator pauses with the arm extended, zero velocity plus high effort from gravity is indistinguishable from zero velocity plus high effort from an obstacle.
The common failure mode is clear: the combined motor current signal ej includes a gravitational component gj (q) that depends on joint configuration q. Without computing gj (q) via inverse dynamics (e.g., Recursive Newton-Euler [30]), there is no way to isolate the contact force component. This explains why industrial bilateral systems use either dedicated force sensors or accurate dynamics models [17]—and why existing low-cost systems have avoided bilateral feedback entirely. We consider this characterisation itself a contribution: it establishes a necessary condition for robust sensorless bilateral control and explains clearly why commodity servos cannot achieve it without additional computation.

VI. DISCUSSION

A. Comparison with Existing Systems
Table II positions our system against related work. We are, to our knowledge, the only system that combines custombuilt scaled followers, bilateral force feedback, and bimanual operation below $5,000.
B. Lessons for Systems Builders
Three practical lessons emerged:
Integration dominates. Individual subsystems (teleop, force feedback, collision avoidance) each worked in isolation. Combining four arms into a single ROS 2 graph exposed namespace leaks, udev conflicts, and startup race conditions that took longer to resolve than any individual feature. The gap between “one pair works” and “two pairs work reliably” was wider than any individual subsystem challenge. Hardware limitations propagate. The gripper’s gearbox friction (the dominant user complaint) is a mechanical property of the XL430 motor, not a software issue. The mixed motor configuration saved 55% on costs but prevented uniform gravity compensation: XL430 motors lack the current control mode needed for model-based torque estimation. No amount of algorithmic tuning can fix hardware-fundamental constraints. Identifying which limitations are hardware-fundamental versus software-addressable saves engineering time.
Negative results are load-bearing. Our three failed force feedback approaches each reveal a different facet of the gravity-contact ambiguity. Documenting why they fail provides more actionable guidance than documenting only the approach that worked.

VII. CONCLUSION
We presented a low-cost bilateral teleoperation system that achieves sensorless force feedback using motor current readings from commodity Dynamixel servos. The system pairs standard PincherX-100 leaders with custom 2×-scaled 3D-printed followers using a torque-tiered motor design, achieving bimanual bilateral teleoperation at ∼$3,000—an order of magnitude cheaper than comparable systems. A user study demonstrated 91.1% obstacle detection sensitivity and strong perceived learnability (median 7/7). We characterised the fundamental gravity-contact ambiguity that limits sensorless bilateral control and documented three alternative approaches that fail to resolve it, establishing that a dynamics model is a necessary condition for robust force estimation on commodity hardware.
Future work. Gravity compensation via Recursive Newton-Euler inverse dynamics would address the core limitation. Lower gear-ratio motors or series elastic actuators would reduce electromagnetic braking. The system’s 1:1 joint-space mapping and ROS 2 architecture make it directly compatible with imitation learning frameworks such as ACT [3] and LeRobot [11], where bilateral demonstrations could improve policy quality [8].

ACKNOWLEDGEMENTS
The author thanks Garry Ellard for supervision and guidance throughout this project, and the 22 user study participants. This work was conducted as a final-year undergraduate dissertation at the University of Edinburgh.

REFERENCES

[1] R. C. Goertz, “Master-slave manipulator,” Argonne National Laboratory, Tech. Rep. ANL-HDY-135, 1949.
[2] ——, “Electronically controlled manipulator,” Nucleonics, vol. 12, no. 11, pp. 46–49, 1954.
[3] T. Z. Zhao, V. Kumar, S. Levine, and C. Finn, “Learning fine-grained bimanual manipulation with low-cost hardware,” in Robotics: Science and Systems (RSS), 2023.
[4] P. Wu, Y. Shentu, Z. Yi, X. Lin, and P. Abbeel, “GELLO: A general, low-cost, and intuitive teleoperation framework for robot manipulators,” 2024 IEEE/RSJ International Conference on Intelligent Robots and Systems (IROS), pp. 12 156–12 163, 2024.

[5] A. Koch, “Low cost robot arm,” 2024, open-source hardware project. [Online]. Available: https://github.com/AlexanderKoch-Koch/low cost robot (https://github.com/AlexanderKoch-Koch/low_cost_robot)
[6] F. Badalkhani-Khamseh et al., “Echo: Open-source low-cost teleoperation with force feedback,” 2025.
[7] S. Sujit, L. Nunziante, D. Lillrank, R. Fernand, J. Dossa, and K. Arulkumaran, “Improving low-cost teleoperation: Augmenting GELLO with force,” 2025.
[8] M. Kobayashi, T. Kanai, and T. Matsubara, “ALPHA-α and Bi-ACT are all you need: Importance of bilateral teleoperation in imitation learning,” 2024.
[9] T. Kanai and T. Matsubara, “Input-gated bilateral teleoperation,” 2025.
[10] Y. Zou, Z. Zhou, C. Shi, Z. Ye, J. Huang, Y. Ding, and B. Zhao, “U-Arm: Ultra low-cost general teleoperation interface for robot manipulation,” 2025.
[11] R. Cadene, S. Alibert, A. Soare et al., “LeRobot: An open-source library for end-to-end robot learning,” arXiv preprint arXiv:2602.22818, 2025.
[12] D. Lawrence, “Stability and transparency in bilateral teleoperation,” IEEE Transactions on Robotics and Automation, vol. 9, pp. 624–637, 1993.
[13] P. F. Hokayem and M. W. Spong, “Bilateral teleoperation: An historical survey,” Automatica, vol. 42, no. 12, pp. 2035–2057, 2006.
[14] R. J. Anderson and M. W. Spong, “Bilateral control of teleoperators with time delay,” IEEE Transactions on Automatic Control, vol. 34, no. 5, pp. 494–501, 1989.
[15] N. Hogan, “Impedance control: An approach to manipulation,” in American Control Conference, 1985, pp. 304–313.
[16] S. Morante, J. G. Victores, and C. Balaguer, “Force-sensorless friction and gravity compensation for robots,” 2016.
[17] Y. Matsumoto et al., “Fast bilateral teleoperation and imitation learning using sensorless force control via accurate dynamics model,” 2025.
[18] Trossen Robotics, “PincherX-100 robot arm specifications,” 2024. [Online]. Available: https://docs.trossenrobotics.com/interbotix xsarms docs/specifications/px100.html (https://docs.trossenrobotics.com/interbotix_xsarms_docs/specifications/px100.html)
[19] ROBOTIS, “DYNAMIXEL XL430-W250 e-manual,” 2024. [Online]. Available: https://emanual.robotis.com/docs/en/dxl/x/xl430-w250/
[20] S. Macenski, T. Foote, B. Gerkey, C. Lalancette, and W. Woodall, “Robot operating system 2: Design, architecture, and uses in the wild,” Science Robotics, vol. 7, 2022.
[21] K. J. Waldron and C. Hubert, “Scaling of robotic mechanisms,” in Proceedings 2000 ICRA, IEEE International Conference on Robotics and Automation, vol. 1, 2000, pp. 40–45.
[22] K. Dermitzakis, J. P. Carbajal, and J. H. Marden, “Scaling laws in robotics,” Procedia Computer Science, vol. 7, pp. 250–252, 2011.
[23] ROBOTIS, “DYNAMIXEL XM430-W210 e-manual,” 2024. [Online]. Available: https://emanual.robotis.com/docs/en/dxl/x/xm430-w210/
[24] Future Technology Devices International Ltd., “AN232B-04: Data throughput, latency and handshaking,” FTDI, Tech. Rep., 2006.
[25] D. Srikanth and R. Vasudevan, “DC motor damping: A strategy to increase passive stiffness of haptic devices,” in Proceedings of Euro-Haptics 2008, 2008, pp. 43–51.
[26] J. E. Colgate and J. M. Brown, “Factors affecting the z-width of a haptic display,” in Proceedings of the IEEE International Conference on Robotics and Automation, vol. 4, 1994, pp. 3205–3210.
[27] ALOHA 2 Team, “ALOHA 2: An enhanced low-cost hardware for bimanual teleoperation,” 2024.
[28] T. Foote, “tf: The transform library,” in 2013 IEEE Conference on Technologies for Practical Robot Applications (TePRA), 2013, pp. 1– 6.
[29] C. C. Preston and A. M. Colman, “Optimal number of response categories in rating scales,” Acta Psychologica, vol. 104, no. 1, pp. 1–15, 2000.
[30] K. M. Lynch and F. C. Park, Modern Robotics: Mechanics, Planning, and Control. Cambridge University Press, 2017.

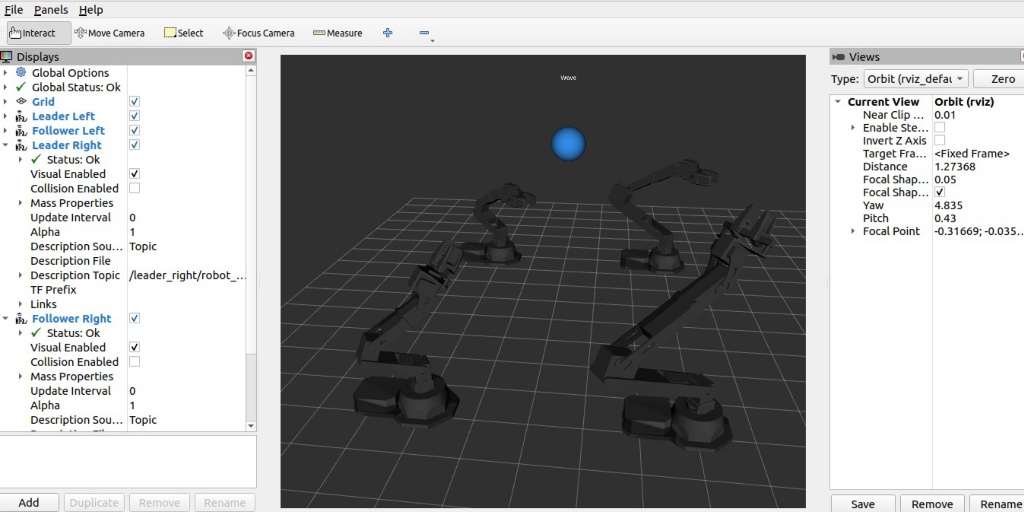
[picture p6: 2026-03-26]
paper/figures/complete-rvis.png

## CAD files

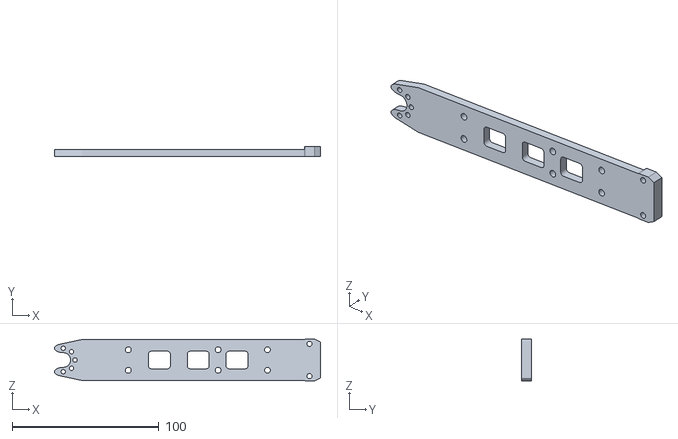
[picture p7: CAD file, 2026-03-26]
3d-printing/modified_arm/final-final-xl-forearm.stl
181.5 x 7.00 x 28.5

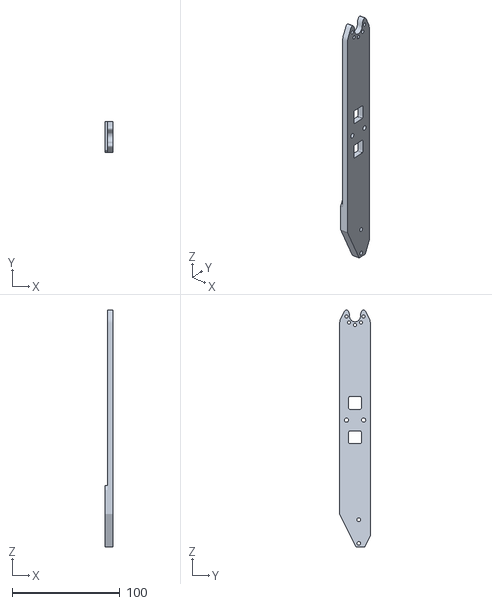
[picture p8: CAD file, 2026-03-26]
3d-printing/modified_arm/left-bicep.stl
7.01 x 28.5 x 220.4

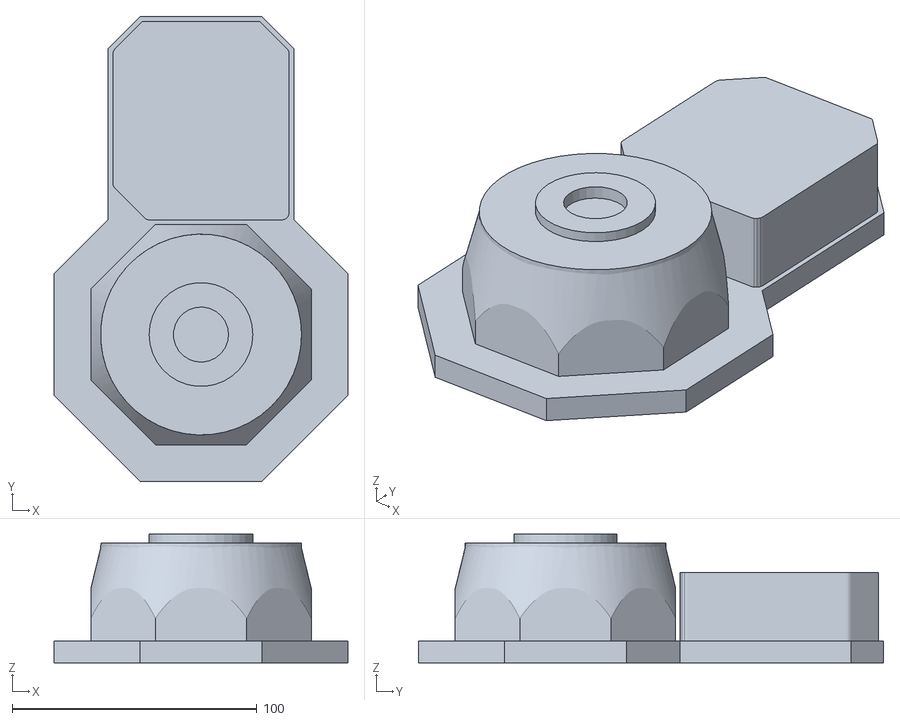
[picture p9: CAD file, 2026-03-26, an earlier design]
3d-printing/archive/px100_1_base.stl
120.0 x 189.8 x 52.6

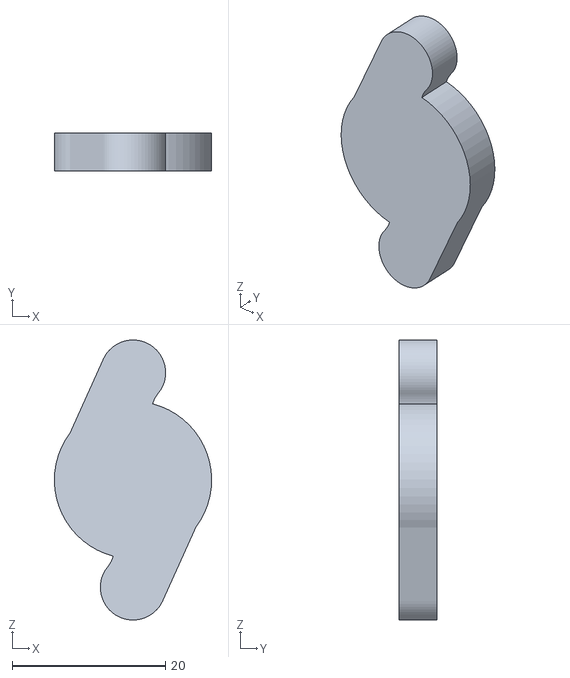
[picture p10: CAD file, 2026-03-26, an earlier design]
3d-printing/archive/px100_6_gripper_prop.stl
20.5 x 5.00 x 36.5

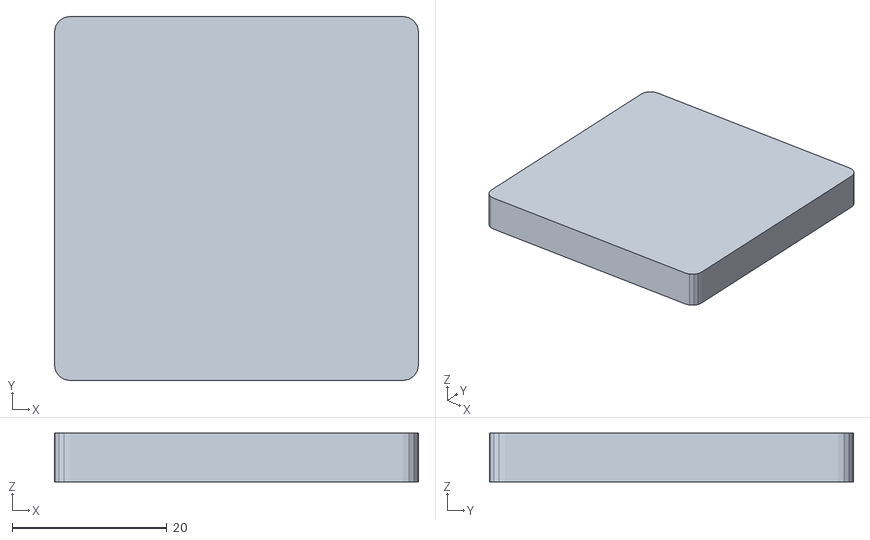
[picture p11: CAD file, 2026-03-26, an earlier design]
3d-printing/archive/px100_9_ar_tag.stl
47.0 x 47.0 x 6.30

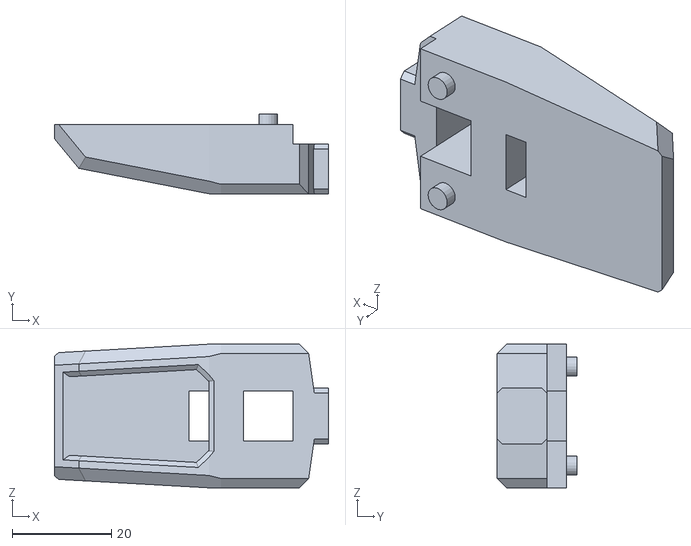
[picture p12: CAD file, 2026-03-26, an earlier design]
3d-printing/archive/px100_8_gripper_finger.stl
55.3 x 16.0 x 29.0

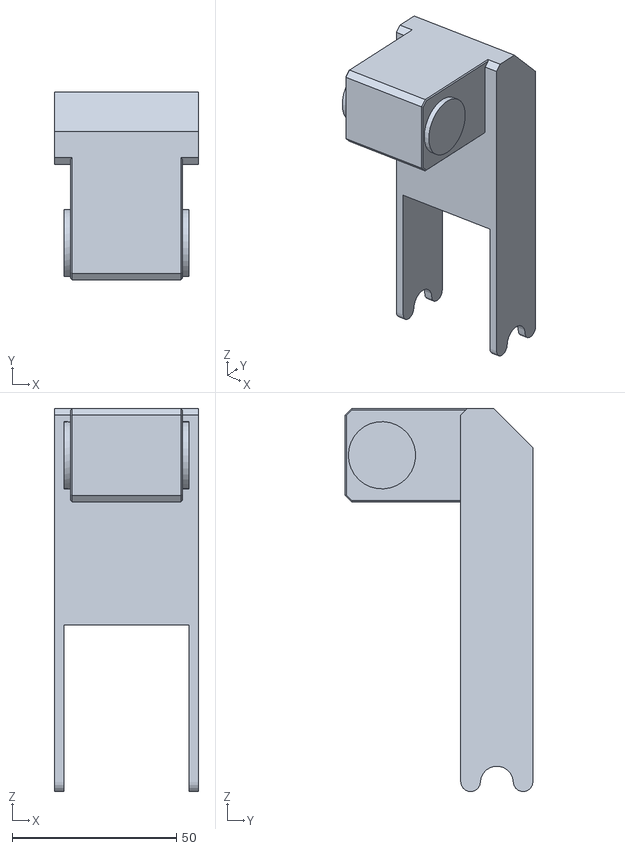
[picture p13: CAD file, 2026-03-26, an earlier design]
3d-printing/archive/px100_3_upper_arm.stl
44.0 x 57.2 x 116.7

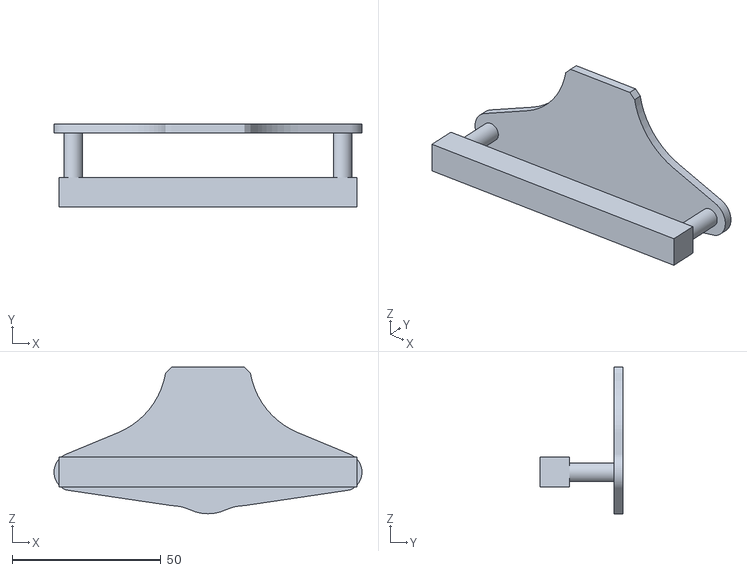
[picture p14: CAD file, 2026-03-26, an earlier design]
3d-printing/archive/px100_7_gripper_bar.stl
103.5 x 28.0 x 49.2

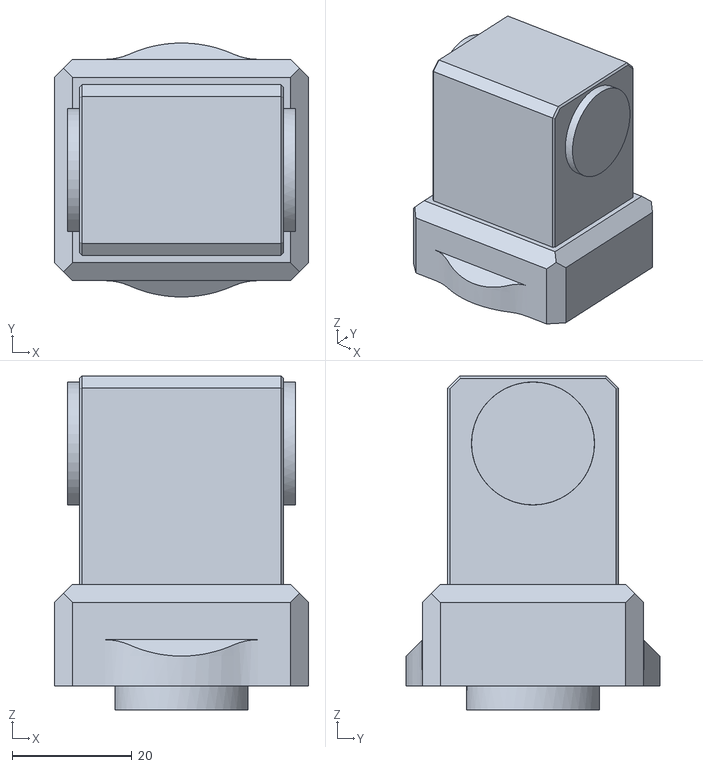
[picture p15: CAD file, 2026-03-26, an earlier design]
3d-printing/archive/px100_2_shoulder.stl
42.4 x 42.3 x 55.7

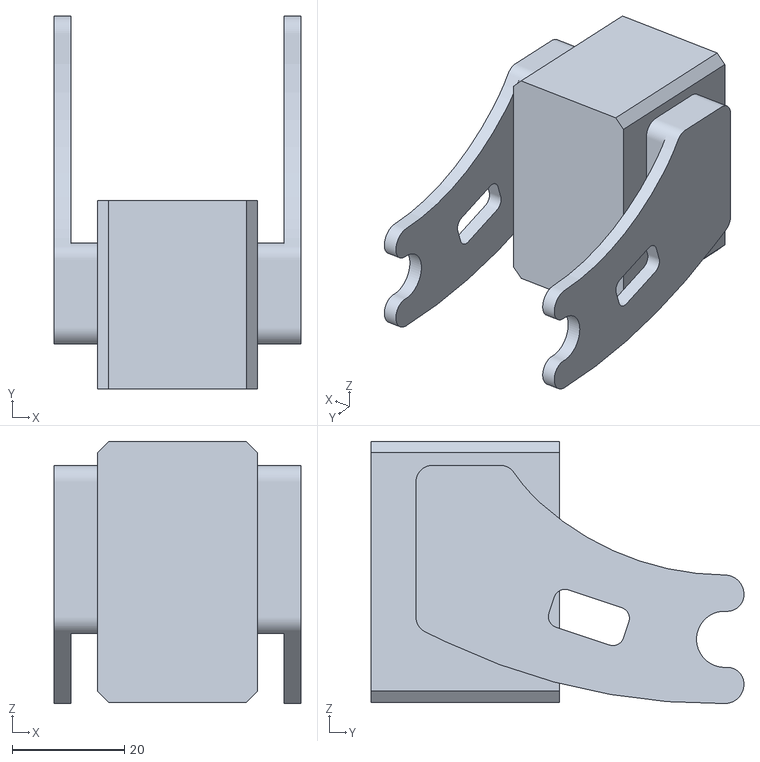
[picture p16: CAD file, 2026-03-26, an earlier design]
3d-printing/archive/px100_5_gripper.stl
44.0 x 66.4 x 46.7

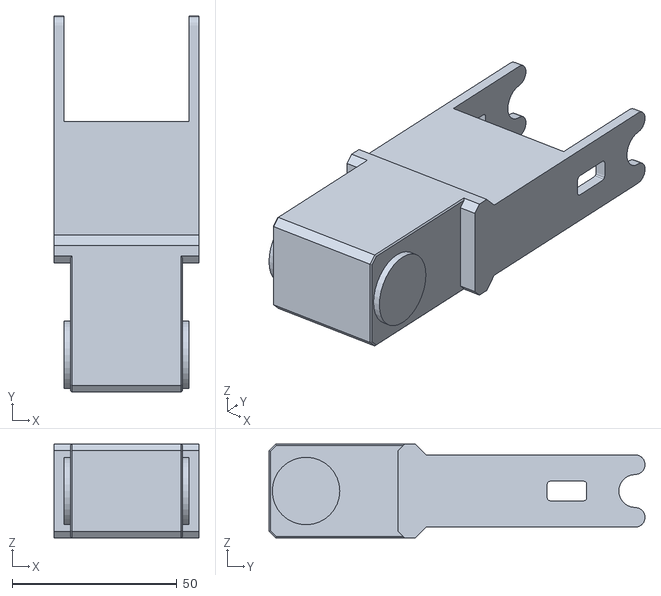
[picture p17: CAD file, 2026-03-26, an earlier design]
3d-printing/archive/px100_4_forearm.stl
44.0 x 114.2 x 28.5

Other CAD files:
3d-printing/modified_arm/right-bicep.stl

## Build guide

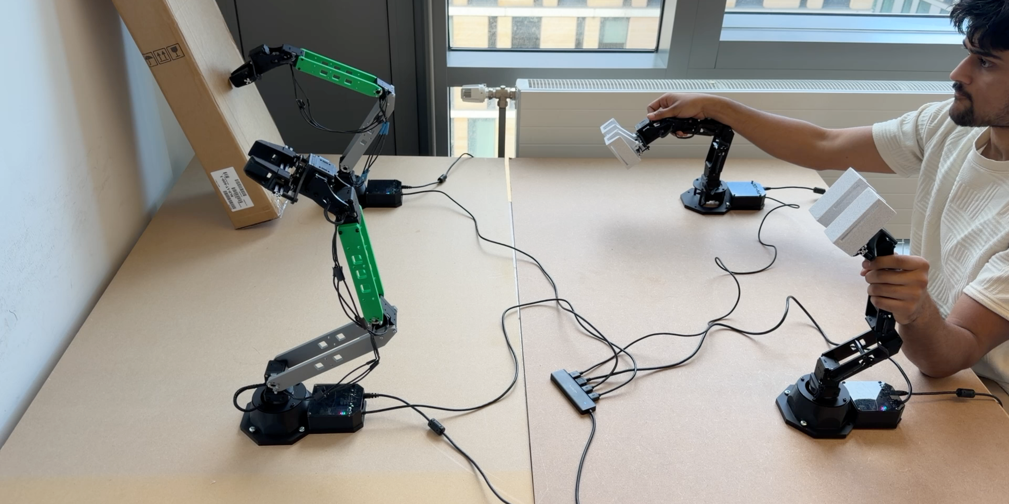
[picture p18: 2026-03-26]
paper/figures/wideshot-usage.png

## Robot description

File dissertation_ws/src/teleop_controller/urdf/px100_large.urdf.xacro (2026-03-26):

<?xml version="1.0"?>
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
<robot name="px100_large" xmlns:xacro="http://ros.org/wiki/xacro">

  <xacro:property name="robot_model" value="px100" scope="global"/>
  <xacro:property name="dof" value="4" scope="global"/>

  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
  <xacro:property name="bicep_scale" value="2.0"/>
  <xacro:property name="forearm_scale" value="2.0"/>

  <xacro:arg name="robot_name" default="px100_large"/>
  <xacro:arg name="base_link_frame" default="base_link"/>
  <xacro:arg name="use_gripper" default="true"/>
  <xacro:arg name="show_ar_tag" default="false"/>
  <xacro:arg name="show_gripper_bar" default="true"/>
  <xacro:arg name="show_gripper_fingers" default="true"/>
  <xacro:arg name="use_world_frame" default="false"/>
  <xacro:arg name="external_urdf_loc" default=""/>
  <xacro:arg name="hardware_type" default="actual"/>

  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
  <xacro:property name="mesh_directory" value="package://interbotix_xsarm_descriptions/meshes/px100_meshes"/>
  <xacro:property name="urdf_loc" value="$(arg external_urdf_loc)"/>
  <xacro:property name="hardware_type" value="$(arg hardware_type)"/>
  <xacro:property name="pi_offset" value="0.00001"/>

  <xacro:property name="waist_limit_effort" value="1"/>
  <xacro:property name="waist_limit_lower" value="${-pi + pi_offset}"/>
  <xacro:property name="waist_limit_upper" value="${pi - pi_offset}"/>
  <xacro:property name="waist_limit_vel" value="${pi}"/>

  <xacro:property name="shoulder_limit_effort" value="2"/>
  <xacro:property name="shoulder_limit_lower" value="${radians(-111)}"/>
  <xacro:property name="shoulder_limit_upper" value="${radians(107)}"/>
  <xacro:property name="shoulder_limit_vel" value="${pi}"/>

  <xacro:property name="elbow_limit_effort" value="2"/>
  <xacro:property name="elbow_limit_lower" value="${radians(-121)}"/>
  <xacro:property name="elbow_limit_upper" value="${radians(92)}"/>
  <xacro:property name="elbow_limit_vel" value="${pi}"/>

  <xacro:property name="wrist_angle_limit_effort" value="1"/>
  <xacro:property name="wrist_angle_limit_lower" value="${radians(-100)}"/>
  <xacro:property name="wrist_angle_limit_upper" value="${radians(123)}"/>
  <xacro:property name="wrist_angle_limit_vel" value="${pi}"/>

  <xacro:property name="gripper_limit_vel" value="${pi}"/>

  <xacro:property name="finger_limit_effort" value="5"/>
  <xacro:property name="finger_limit_lower" value="0.015"/>
  <xacro:property name="finger_limit_upper" value="0.037"/>
  <xacro:property name="finger_limit_vel" value="1"/>

  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

  <xacro:if value="$(arg use_world_frame)">
    <link name="world"/>
    <joint name="fixed" type="fixed">
      <parent link="world"/>
      <child link="$(arg robot_name)/$(arg base_link_frame)"/>
    </joint>
  </xacro:if>

  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
  <link name="$(arg robot_name)/$(arg base_link_frame)">
    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
    <inertial>
      <origin rpy="0 0 ${pi/2}" xyz="-0.0332053000 0.0008915770 0.0211913000"/>
      <mass value="0.395887"/>
      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
    </inertial>
  </link>

  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
  <joint name="waist" type="revolute">
    <axis xyz="0 0 1"/>
    <limit effort="${waist_limit_effort}" lower="${waist_limit_lower}" upper="${waist_limit_upper}" velocity="${waist_limit_vel}"/>
    <origin rpy="0 0 0" xyz="0 0 0.05085"/>
    <parent link="$(arg robot_name)/$(arg base_link_frame)"/>
    <child link="$(arg robot_name)/shoulder_link"/>
    <dynamics friction="0.1" damping="0.1"/>
  </joint>

  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
  <link name="$(arg robot_name)/shoulder_link">
    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
    <inertial>
      <origin rpy="0 0 ${pi/2}" xyz="0.0000111169 -0.0003605640 0.0284598000"/>
      <mass value="0.072587"/>
      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
    </inertial>
  </link>

  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
  <joint name="shoulder" type="revolute">
    <axis xyz="0 1 0"/>
    <limit effort="${shoulder_limit_effort}" lower="${shoulder_limit_lower}" upper="${shoulder_limit_upper}" velocity="${shoulder_limit_vel}"/>
    <origin rpy="0 0 0" xyz="0 0 0.04225"/>
    <parent link="$(arg robot_name)/shoulder_link"/>
    <child link="$(arg robot_name)/upper_arm_link"/>
    <dynamics friction="0.1" damping="0.1"/>
  </joint>

  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
  <link name="$(arg robot_name)/upper_arm_link">
    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
    <inertial>
      <origin rpy="0 0 ${pi/2}" xyz="${0.0161976963} ${-0.0002929352} ${0.0877230000 * bicep_scale}"/>
      <mass value="${0.082923 * bicep_scale}"/>
      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
    </inertial>
  </link>

  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
  <joint name="elbow" type="revolute">
    <axis xyz="0 1 0"/>
    <limit effort="${elbow_limit_effort}" lower="${elbow_limit_lower}" upper="${elbow_limit_upper}" velocity="${elbow_limit_vel}"/>
    <origin rpy="0 0 0" xyz="0.035 0 ${0.1 * bicep_scale}"/>
    <parent link="$(arg robot_name)/upper_arm_link"/>
    <child link="$(arg robot_name)/forearm_link"/>
    <dynamics friction="0.1" damping="0.1"/>
  </joint>

  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
  <link name="$(arg robot_name)/forearm_link">
    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
    <inertial>
      <origin rpy="0 0 ${pi/2}" xyz="${0.0773720000 * forearm_scale} ${-0.0003324882} 0.0000000000"/>
      <mass value="${0.073058 * forearm_scale}"/>
      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
    </inertial>
  </link>

  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

  <xacro:if value="$(arg use_gripper)">

    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
    <joint name="wrist_angle" type="revolute">
      <axis xyz="0 1 0"/>
      <limit effort="${wrist_angle_limit_effort}" lower="${wrist_angle_limit_lower}" upper="${wrist_angle_limit_upper}" velocity="${wrist_angle_limit_vel}"/>
      <origin rpy="0 0 0" xyz="${0.1 * forearm_scale} 0 0"/>
      <parent link="$(arg robot_name)/forearm_link"/>
      <child link="$(arg robot_name)/gripper_link"/>
      <dynamics friction="0.1" damping="0.1"/>
    </joint>

    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
    <link name="$(arg robot_name)/gripper_link">
      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
      <inertial>
        <origin rpy="0 0 ${pi/2}" xyz="0.0446910000 0.0000000000 0.0113540000"/>
        <mass value="0.069929"/>
        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
      </inertial>
    </link>

    <joint name="ee_arm" type="fixed">
      <axis xyz="1 0 0"/>
      <origin rpy="0 0 0" xyz="0.063 0 0"/>
      <parent link="$(arg robot_name)/gripper_link"/>
      <child link="$(arg robot_name)/ee_arm_link"/>
    </joint>

    <link name="$(arg robot_name)/ee_arm_link">
      <inertial>
        <mass value="0.001"/>
        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
      </inertial>
    </link>

    <joint name="gripper" type="continuous">
      <axis xyz="1 0 0"/>
      <limit effort="1" velocity="${gripper_limit_vel}"/>
      <origin rpy="0 0 0" xyz="0.0055 0 0"/>
      <parent link="$(arg robot_name)/ee_arm_link"/>
      <child link="$(arg robot_name)/gripper_prop_link"/>
      <dynamics friction="0.1" damping="0.1"/>
    </joint>

    <link name="$(arg robot_name)/gripper_prop_link">
      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
      <inertial>
        <origin rpy="0 0 ${pi/2}" xyz="0.0008460000 -0.0000019330 0.0000420000"/>
        <mass value="0.00434"/>
        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
      </inertial>
    </link>

    <xacro:if value="$(arg show_gripper_bar)">

      <joint name="gripper_bar" type="fixed">
        <axis xyz="1 0 0"/>
        <origin rpy="0 0 0" xyz="0 0 0"/>
        <parent link="$(arg robot_name)/ee_arm_link"/>
        <child link="$(arg robot_name)/gripper_bar_link"/>
      </joint>

      <link name="$(arg robot_name)/gripper_bar_link">
        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
        <inertial>
          <origin rpy="0 0 ${pi/2}" xyz="0.0096870000 0.0000005660 0.0049620000"/>
          <mass value="0.034199"/>
          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
        </inertial>
      </link>

      <joint name="ee_bar" type="fixed">
        <axis xyz="1 0 0"/>
        <origin rpy="0 0 0" xyz="0.023 0 0"/>
        <parent link="$(arg robot_name)/gripper_bar_link"/>
        <child link="$(arg robot_name)/fingers_link"/>
      </joint>

      <link name="$(arg robot_name)/fingers_link">
        <inertial>
          <mass value="0.001"/>
          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
        </inertial>
      </link>

      <xacro:if value="$(arg show_gripper_fingers)">
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

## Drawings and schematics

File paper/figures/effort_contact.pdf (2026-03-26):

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

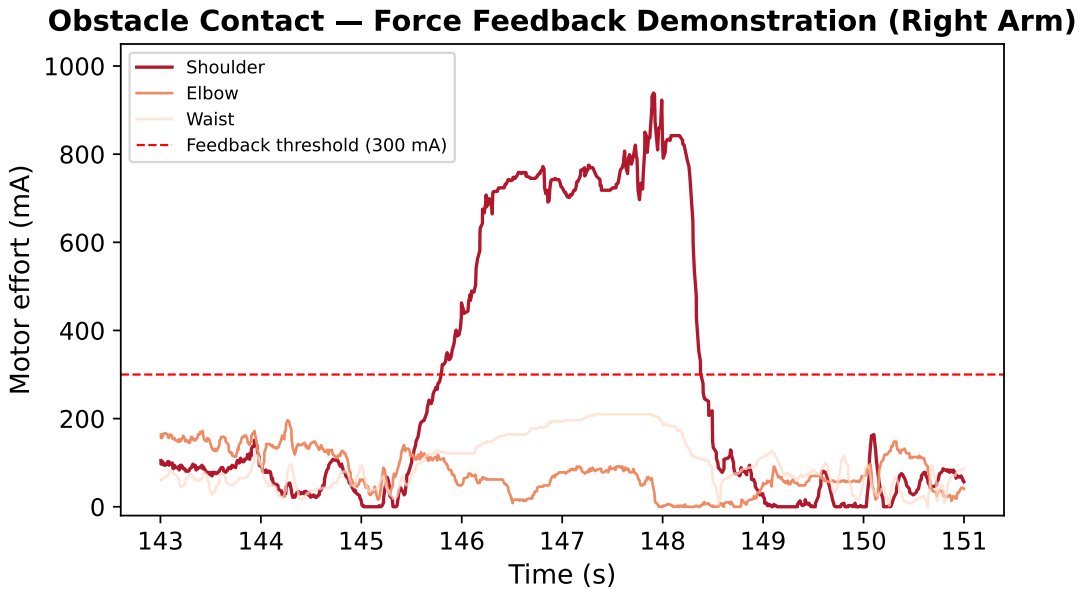
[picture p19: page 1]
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

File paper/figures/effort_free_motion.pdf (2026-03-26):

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

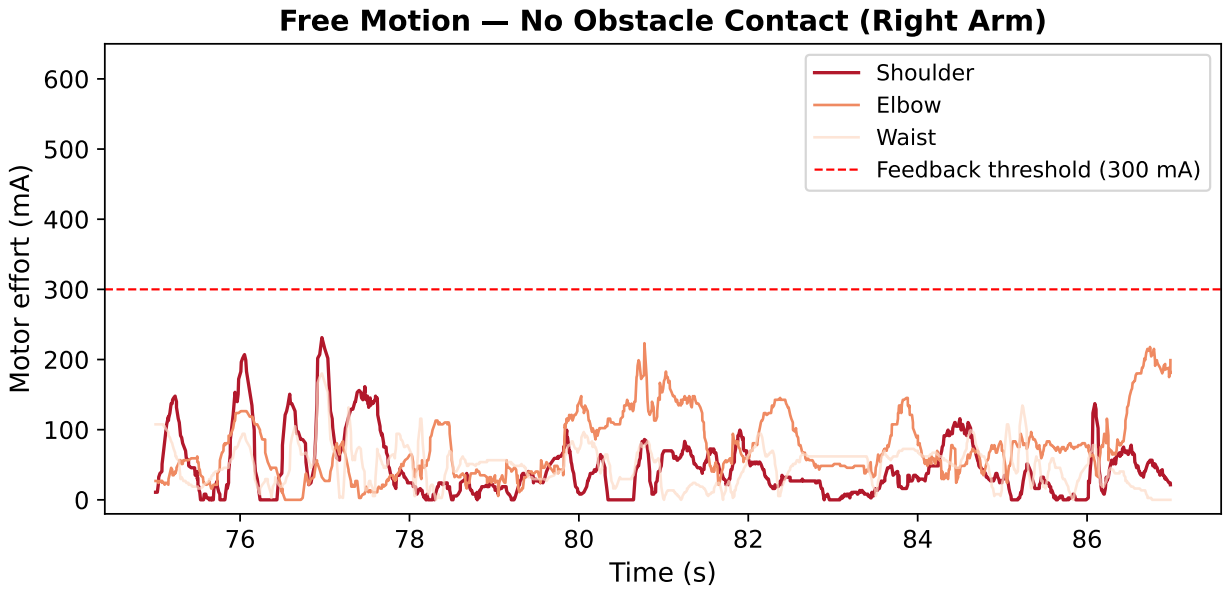
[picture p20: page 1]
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

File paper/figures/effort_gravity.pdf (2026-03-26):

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

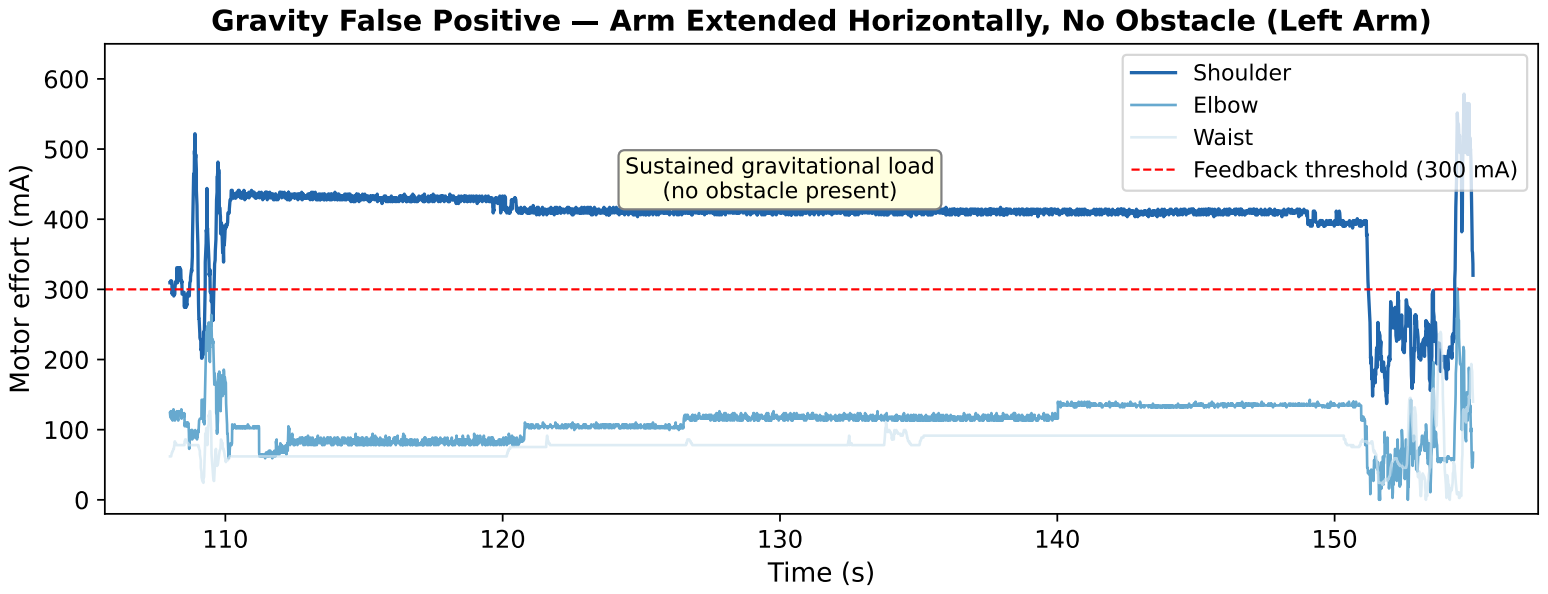
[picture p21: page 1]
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

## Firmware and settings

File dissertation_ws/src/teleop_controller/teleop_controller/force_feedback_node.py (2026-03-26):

#!/usr/bin/env python3
"""
Force Feedback Node

Reads effort (motor current) from follower joint states and sends proportional
opposing PWM to the leader arm when effort exceeds a threshold.

Known limitation: cannot distinguish gravity from obstacles (both cause high
effort), so works best when the arm is near vertical.
"""

import rclpy
from rclpy.node import Node
from sensor_msgs.msg import JointState
from std_msgs.msg import Bool
from interbotix_xs_msgs.srv import RegisterValues, TorqueEnable

ARM_JOINTS = ['waist', 'shoulder', 'elbow', 'wrist_angle']


class ForceFeedbackNode(Node):
    def __init__(self):
        super().__init__('force_feedback_node')

        self.declare_parameter('leader_name', 'leader')
        self.declare_parameter('follower_name', 'follower')

        self.leader_name = self.get_parameter('leader_name').value
        self.follower_name = self.get_parameter('follower_name').value

        self.declare_parameter('enabled', True)
        self.declare_parameter('effort_threshold', 150.0)
        self.declare_parameter('max_pwm', 350.0)
        self.declare_parameter('pwm_scale', 0.5)
        self.declare_parameter('smoothing_factor', 0.15)
        self.declare_parameter('pwm_deadband', 20)
        self.declare_parameter('update_rate', 30.0)

        self.enabled = self.get_parameter('enabled').value
        self.effort_threshold = self.get_parameter('effort_threshold').value
        self.max_pwm = self.get_parameter('max_pwm').value
        self.pwm_scale = self.get_parameter('pwm_scale').value
        self.smoothing_factor = self.get_parameter('smoothing_factor').value
        self.pwm_deadband = self.get_parameter('pwm_deadband').value
        self.update_rate = self.get_parameter('update_rate').value
        self.startup_service_timeout = 15.0  # seconds

        self.follower_effort = {j: 0.0 for j in ARM_JOINTS}
        self.current_pwm = {j: 0.0 for j in ARM_JOINTS}
        self.last_pwm_sent = {j: 0 for j in ARM_JOINTS}

        self.motion_active = False
        self.create_subscription(Bool, '/motion_active', self._motion_active_cb, 10)

        self.last_follower_time = self.get_clock().now()
        self.watchdog_timeout = 1.0

        self.pwm_client = self.create_client(
            RegisterValues,
            f'/{self.leader_name}/set_motor_registers'
        )

        self.torque_client = self.create_client(
            TorqueEnable,
            f'/{self.leader_name}/torque_enable'
        )

        self._wait_for_service(
            self.pwm_client,
            f'/{self.leader_name}/set_motor_registers',
            self.startup_service_timeout,
        )
        self._wait_for_service(
            self.torque_client,
            f'/{self.leader_name}/torque_enable',
            self.startup_service_timeout,
        )

        self.set_arm_torque(self.enabled)

        self.follower_sub = self.create_subscription(
            JointState,
            f'/{self.follower_name}/joint_states',
            self.follower_callback,
            10
        )

        self.timer = self.create_timer(1.0 / self.update_rate, self.control_loop)

        self.get_logger().info('=' * 50)
        self.get_logger().info(f'FORCE FEEDBACK: {self.leader_name} <- {self.follower_name}')
        self.get_logger().info(f'Enabled: {self.enabled}')
        self.get_logger().info(f'Effort threshold: {self.effort_threshold} mA')
        self.get_logger().info(f'PWM scale: {self.pwm_scale}, Max: {self.max_pwm}')
        self.get_logger().info(f'Smoothing: {self.smoothing_factor}')
        self.get_logger().info('=' * 50)

    def _wait_for_service(self, client, service_name: str, timeout_sec: float):
        self.get_logger().info(f'Waiting for {service_name} service...')
        waited = 0.0
        while rclpy.ok() and not client.wait_for_service(timeout_sec=1.0):
            waited += 1.0
            self.get_logger().info(
                f'Still waiting for {service_name} ({waited:.0f}s/{timeout_sec:.0f}s)...'
            )
            if waited >= timeout_sec:
                raise RuntimeError(
                    f'Timed out waiting for {service_name}; '
                    'leader arm/service is not available.'
                )

        if not rclpy.ok():
            raise RuntimeError(f'Shutdown requested while waiting for {service_name}')

    def follower_callback(self, msg: JointState):
        self.last_follower_time = self.get_clock().now()
        for i, name in enumerate(msg.name):
            if name in ARM_JOINTS and i < len(msg.effort):
                self.follower_effort[name] = msg.effort[i]

    def _motion_active_cb(self, msg: Bool):
        self.motion_active = msg.data

    def control_loop(self):
        if self.motion_active:
            for joint in ARM_JOINTS:
                self.send_pwm(joint, 0)
            return

        if not self.enabled:
            for joint in ARM_JOINTS:
                self.send_pwm(joint, 0)
            return

        time_since_follower = (
            self.get_clock().now() - self.last_follower_time
        ).nanoseconds / 1e9

        if time_since_follower > self.watchdog_timeout:
            for joint in ARM_JOINTS:
                self.send_pwm(joint, 0)
            return

        for joint in ARM_JOINTS:
            effort = self.follower_effort.get(joint, 0.0)

            target_pwm = 0.0
            if abs(effort) >= self.effort_threshold:
                effort_above_threshold = abs(effort) - self.effort_threshold
                pwm_magnitude = min(effort_above_threshold * self.pwm_scale, self.max_pwm)

                if effort > 0:
                    target_pwm = -pwm_magnitude
                else:
                    target_pwm = pwm_magnitude

            self.current_pwm[joint] = (
                self.smoothing_factor * target_pwm +
                (1 - self.smoothing_factor) * self.current_pwm[joint]
            )

            pwm_to_send = int(self.current_pwm[joint])

            if abs(pwm_to_send - self.last_pwm_sent[joint]) >= self.pwm_deadband:
                if abs(pwm_to_send) > 10:
                    self.get_logger().info(f'{joint}: effort={effort:+.0f}mA → PWM={pwm_to_send:+d}')
                self.send_pwm(joint, pwm_to_send)

    def send_pwm(self, joint_name: str, pwm_value: int):
        if pwm_value == self.last_pwm_sent[joint_name]:
            return

        self.last_pwm_sent[joint_name] = pwm_value

        request = RegisterValues.Request()
        request.cmd_type = 'single'
        request.name = joint_name
        request.reg = 'Goal_PWM'
        request.value = pwm_value
        self.pwm_client.call_async(request)

    def set_arm_torque(self, enable: bool):
        """Enable/disable torque on leader arm joints (not gripper)."""
        request = TorqueEnable.Request()
        request.cmd_type = 'group'
        request.name = 'arm'
        request.enable = enable
        self.torque_client.call_async(request)
        if enable:
            self.get_logger().info('Arm torque ENABLED (force feedback active, arm resists)')
        else:
            self.get_logger().info('Arm torque DISABLED (easy to move)')

    def shutdown(self):
        self.get_logger().info('Shutting down - disabling torque and zeroing PWM')
        self.set_arm_torque(False)
        for joint in ARM_JOINTS:
            request = RegisterValues.Request()
            request.cmd_type = 'single'
            request.name = joint
            request.reg = 'Goal_PWM'
            request.value = 0
            self.pwm_client.call_async(request)


def main(args=None):
    rclpy.init(args=args)
    node = ForceFeedbackNode()

    try:
        rclpy.spin(node)
    except KeyboardInterrupt:
        pass
    finally:
        node.shutdown()
        node.destroy_node()
        rclpy.shutdown()


if __name__ == '__main__':
    main()

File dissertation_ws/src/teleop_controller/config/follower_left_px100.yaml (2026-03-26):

port: /dev/ttyDXL1

joint_order: [waist, shoulder, elbow, wrist_angle, gripper]
sleep_positions: [0, -1.88, 1.5, 0.8, 0]

joint_state_publisher:
  update_rate: 100
  publish_states: true
  topic_name: joint_states

groups:
  arm: [waist, shoulder, elbow, wrist_angle]
  gripper: [gripper]

grippers:
  gripper:
    horn_radius: 0.014
    arm_length: 0.024
    left_finger: left_finger
    right_finger: right_finger

shadows:

sisters:

motors:
  waist:
    ID: 1
    Baud_Rate: 3
    Return_Delay_Time: 0
    Drive_Mode: 0
    Velocity_Limit: 131
    Min_Position_Limit: 0
    Max_Position_Limit: 4095
    Secondary_ID: 255

  shoulder:
    ID: 2
    Baud_Rate: 3
    Return_Delay_Time: 0
    Drive_Mode: 1
    Velocity_Limit: 131
    Min_Position_Limit: 784
    Max_Position_Limit: 3265
    Secondary_ID: 255

  elbow:
    ID: 3
    Baud_Rate: 3
    Return_Delay_Time: 0
    Drive_Mode: 1
    Velocity_Limit: 131
    Min_Position_Limit: 671
    Max_Position_Limit: 3094
    Secondary_ID: 255

  wrist_angle:
    ID: 4
    Baud_Rate: 3
    Return_Delay_Time: 0
    Drive_Mode: 1
    Velocity_Limit: 131
    Min_Position_Limit: 910
    Max_Position_Limit: 3447
    Secondary_ID: 255

  gripper:
    ID: 5
    Baud_Rate: 3
    Return_Delay_Time: 0
    Drive_Mode: 0
    Velocity_Limit: 131
    Min_Position_Limit: 0
    Max_Position_Limit: 4095
    Secondary_ID: 255
    PWM_Limit: 300

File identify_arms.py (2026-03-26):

#!/usr/bin/env python3
"""
Identify which USB serial port belongs to which arm and create persistent udev rules.

Scans /dev/ttyUSB* ports, reads Dynamixel motor model numbers to distinguish
leader (all XL430) from follower (has XM430 on load-bearing joints). Creates
/dev/ttyDXL* symlinks via udev rules that survive reboots.
"""

import glob
import os
import subprocess
import sys
import time

from dynamixel_sdk import PortHandler, PacketHandler, COMM_SUCCESS

PROTOCOL_VERSION = 2.0
BAUDRATE = 1000000

MODEL_XL430_W250 = 1060
MODEL_XM430_W210 = 1030
MODEL_NAMES = {
    MODEL_XL430_W250: 'XL430-W250',
    MODEL_XM430_W210: 'XM430-W210',
    1000: 'X430-350 (model 1000)',
}

MOTOR_IDS = [1, 2, 3, 4, 5]
ADDR_MODEL_NUMBER = 0

UDEV_RULES_FILE = '/etc/udev/rules.d/99-dynamixel.rules'
UDEV_LINK_PRIORITY = 100

DXL_ASSIGNMENTS = {
    'left':  {'leader': 'ttyDXL0', 'follower': 'ttyDXL1'},
    'right': {'leader': 'ttyDXL2', 'follower': 'ttyDXL3'},
}


def set_usb_latency(port, latency_ms=1):
    """Set USB latency timer (16ms default is too slow for Dynamixel comms)."""
    device = os.path.basename(port)
    latency_file = f'/sys/bus/usb-serial/devices/{device}/latency_timer'
    try:
        with open(latency_file, 'w') as f:
            f.write(str(latency_ms))
    except (PermissionError, FileNotFoundError):
        pass


def get_usb_serial(port):
    try:
        output = subprocess.check_output(
            ['udevadm', 'info', '-a', '-n', port],
            text=True
        )
        for line in output.splitlines():
            line = line.strip()
            if line.startswith('ATTRS{serial}==') and '0000:' not in line:
                return line.split('"')[1]
    except Exception:
        pass
    return None


def scan_port(port):
    set_usb_latency(port)

    port_handler = PortHandler(port)
    packet_handler = PacketHandler(PROTOCOL_VERSION)

    if not port_handler.openPort():
        return {}
    if not port_handler.setBaudRate(BAUDRATE):
        port_handler.closePort()
        return {}

    motors = {}
    for motor_id in MOTOR_IDS:
        model, result, _ = packet_handler.read2ByteTxRx(
            port_handler, motor_id, ADDR_MODEL_NUMBER
        )
        if result == COMM_SUCCESS:
            motors[motor_id] = model

    port_handler.closePort()
    return motors


def identify_arm(motors):
    if not motors:
        return 'unknown'

    if all(m == MODEL_XL430_W250 for m in motors.values()):
        return 'leader'

    # Follower has non-XL motors on load-bearing joints (some report model 1000)
    if any(m != MODEL_XL430_W250 for m in motors.values()):
        return 'follower'

    return 'unknown'


def load_existing_rules():
    existing = {}
    if not os.path.exists(UDEV_RULES_FILE):
        return existing

    try:
        with open(UDEV_RULES_FILE, 'r') as f:
            for line in f:
                line = line.strip()
                if not line or line.startswith('#'):
                    continue
                serial = symlink = None
                for part in line.split(','):
                    part = part.strip()
                    if 'ATTRS{serial}' in part:
                        serial = part.split('"')[1]
                    if 'SYMLINK' in part:
                        symlink = part.split('"')[1]
                if serial and symlink:
                    existing[serial] = symlink
    except PermissionError:
        try:
            output = subprocess.check_output(
                ['sudo', 'cat', UDEV_RULES_FILE], text=True
            )
            for line in output.splitlines():
                line = line.strip()
                if not line or line.startswith('#'):
                    continue
                serial = symlink = None
                for part in line.split(','):
                    part = part.strip()
                    if 'ATTRS{serial}' in part:
                        serial = part.split('"')[1]
                    if 'SYMLINK' in part:
                        symlink = part.split('"')[1]
                if serial and symlink:
                    existing[serial] = symlink
        except Exception:
            pass

    return existing


def build_rules_content(rules):
    lines = [
        '# Dynamixel USB adapters - auto-generated by identify_arms.py',
        '# Maps USB serial numbers to /dev/ttyDXL* symlinks',
        '#',
    ]
    for serial, (symlink, comment) in sorted(rules.items(), key=lambda x: x[1][0]):
        lines.append(f'# {comment}')
        lines.append(
            f'SUBSYSTEM=="tty", ATTRS{{serial}}=="{serial}", '
            f'SYMLINK+="{symlink}", ATTR{{latency_timer}}="1", '
            f'OPTIONS+="link_priority={UDEV_LINK_PRIORITY}"'
        )
        lines.append('')

    return '\n'.join(lines) + '\n'


def sudo_write_file(path, content):
    proc = subprocess.run(
        ['sudo', 'tee', path],
        input=content, text=True,
        stdout=subprocess.DEVNULL
    )
    return proc.returncode == 0


def refresh_udev_symlinks():
    for i in range(4):
        link = f'/dev/ttyDXL{i}'
        if os.path.islink(link):
            subprocess.run(['sudo', 'rm', link], check=False)

    subprocess.run(['sudo', 'udevadm', 'control', '--reload-rules'], check=True)
    subprocess.run(['sudo', 'udevadm', 'trigger'], check=True)
    time.sleep(1)


def rewrite_existing_rules(existing_rules, dry_run=False):
    all_rules = {
        serial: (symlink, '(preserved mapping)')
        for serial, symlink in existing_rules.items()
    }
    content = build_rules_content(all_rules)

    if dry_run:
        print('--dry-run: would rewrite udev rules using current format.')
        return

    print(f'Rewriting {UDEV_RULES_FILE} with link_priority={UDEV_LINK_PRIORITY}...')
    if not sudo_write_file(UDEV_RULES_FILE, content):
        print('ERROR: Failed to rewrite udev rules.')
        sys.exit(1)
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

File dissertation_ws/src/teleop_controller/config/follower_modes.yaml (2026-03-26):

# This file is for the FOLLOWER arm.
# It keeps the arm AND GRIPPER in 'position' mode, but makes them move very fast.
groups:
  arm:
    operating_mode: 'position'
    profile_type: 'time'
    profile_velocity: 50       # Total move time: 50ms (fast)
    profile_acceleration: 10   # Accel time: 10ms (safe, non-zero)
  gripper:
    # --- THIS IS THE FIX ---
    operating_mode: 'position'
    profile_type: 'time'
    profile_velocity: 50
    profile_acceleration: 10

singles:
  gripper:
    # --- THIS IS THE FIX (for consistency) ---
    operating_mode: 'position'
    profile_type: 'time'
    profile_velocity: 50
    profile_acceleration: 10
